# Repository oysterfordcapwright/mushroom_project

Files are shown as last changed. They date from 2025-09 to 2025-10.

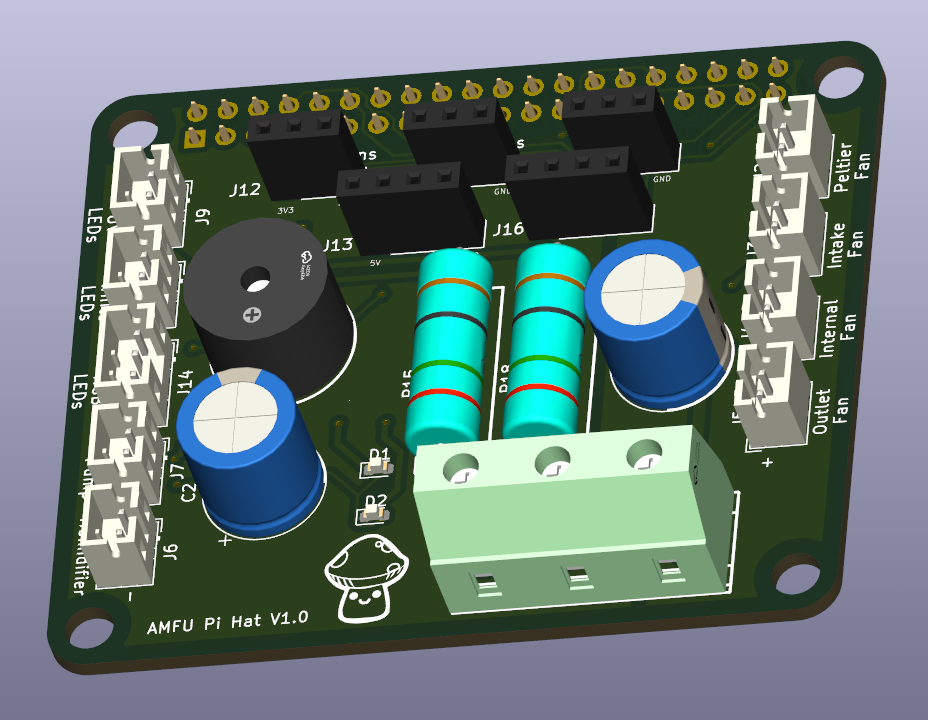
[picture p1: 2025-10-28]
hardware_design/proposed_pcb/pcb_images/PCB_3D_View.png

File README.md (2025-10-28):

# Automated Mushroom Fruiting Unit (AMFU)

A Raspberry Pi-based automated environmental control system for mushroom cultivation. This project provides precise control over temperature, humidity, CO₂ levels, and lighting to create optimal fruiting conditions for various mushroom species.

AMFU in action 

## Project Overview

The AMFU is a self-contained system that automates the fruiting stage of mushroom cultivation. It features a web-based interface for remote monitoring and control, making mushroom growing more accessible and reliable for both hobbyists and small-scale growers.

## Repository Structure

### Core Software
- **Flask Application** - Friendly web interface for system control and monitoring
- **Component Libraries** - Python drivers for all sensors and actuators:
  - Temperature and humidity sensors (DS18B20, DHT22)
  - CO₂ sensor (MH-Z19B) 
  - Lighting control (Neopixel, custom LED circuits)
  - Actuator drivers (Peltier, fans, servos, humidifier)
- **Control System** - Smart environmental management that handles parameter conflicts

### Hardware Design
- **CAD Models** - 3D printable enclosure components and mounting brackets
- **PCB Designs** - Custom Raspberry Pi hat for cleaner wiring

### Documentation
- **Component Datasheets** - Technical specifications for all hardware
- **Mushroom Results** - Yield after 1 week
- **Timelapse Examples** - Watch the mushrooms grow!

## Key Features

- **Multi-parameter control** - Temperature, humidity, CO₂, and lighting all managed automatically
- **Web-based access** - Monitor and adjust conditions from any device
- **Real-time data logging** - Watch your environmental parameters live
- **Automated time-lapse** - Capture your mushroom's growth journey
- **Contamination control** - HEPA filtration keeps chamber isolated

## Perfect For

- Home mushroom cultivation enthusiasts
- Educators teaching controlled environment agriculture
- Small-scale specialty mushroom producers
- Anyone fascinated with environmental automation

---

*Happy growing!* 🍄

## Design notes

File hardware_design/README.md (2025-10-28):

Contains the CAD .stl files and KiCad project files designed for the AMFU project.

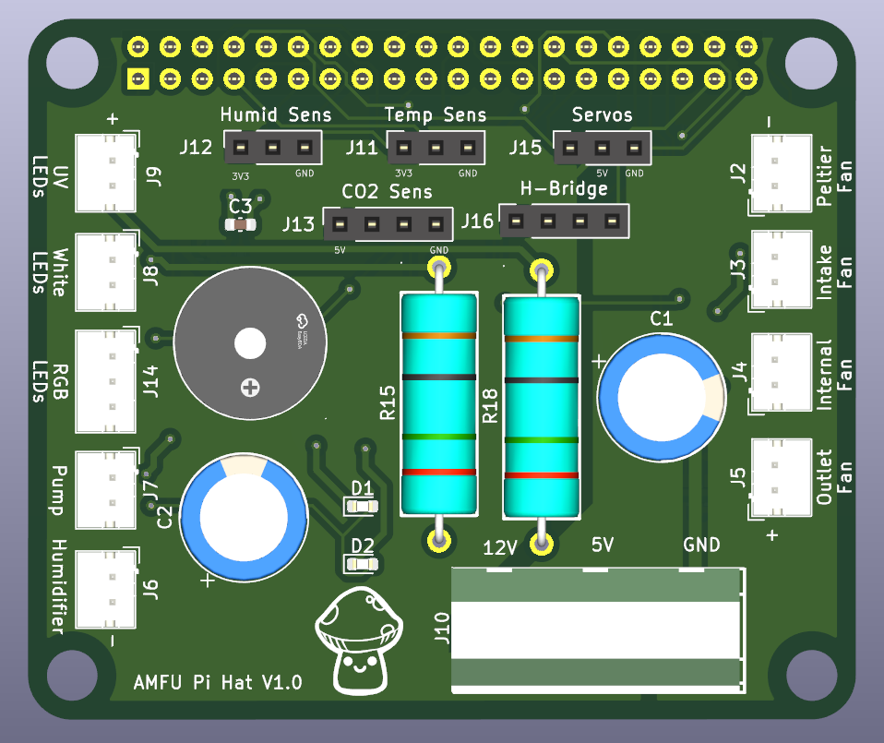
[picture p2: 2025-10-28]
hardware_design/proposed_pcb/pcb_images/PCB_Top_View.png

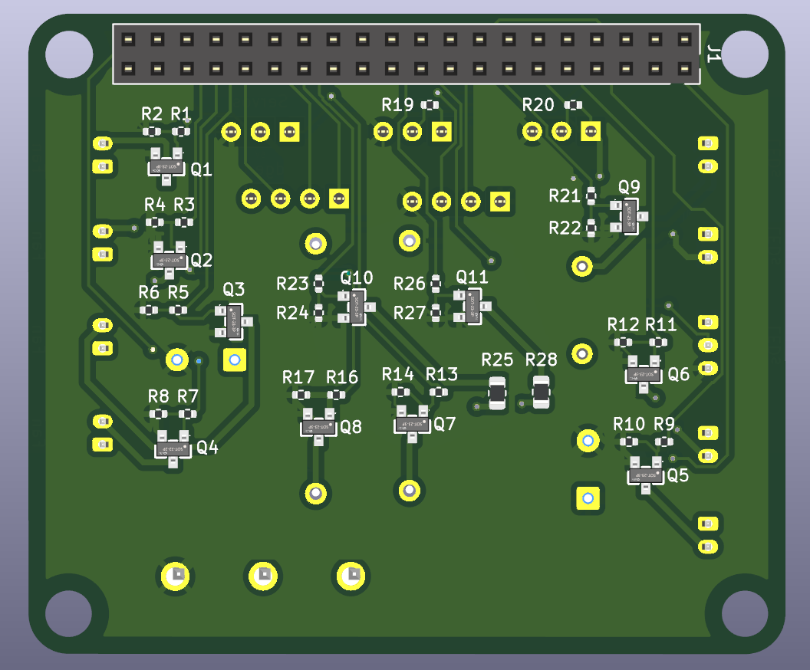
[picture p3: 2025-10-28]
hardware_design/proposed_pcb/pcb_images/PCB_Bottom_View.png

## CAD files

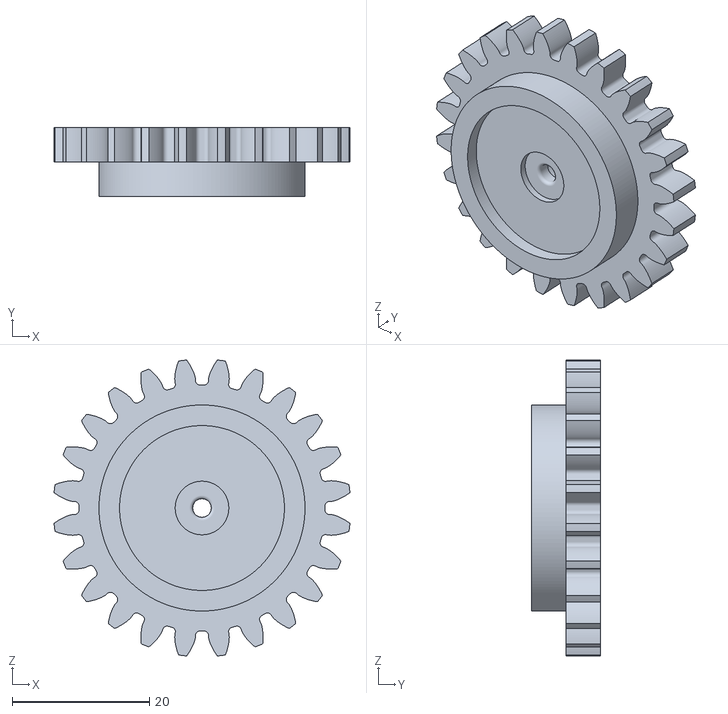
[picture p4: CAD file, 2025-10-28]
hardware_design/3d_cad_files/Airway Slider - Spur Gear.stl
43.1 x 10.0 x 43.1

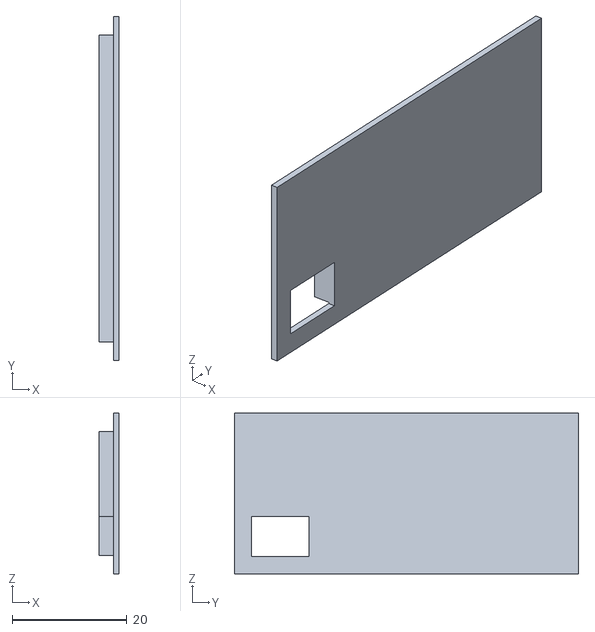
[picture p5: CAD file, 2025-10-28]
hardware_design/3d_cad_files/Humidifier Circuit Housing - Lid.stl
3.50 x 60.0 x 28.0

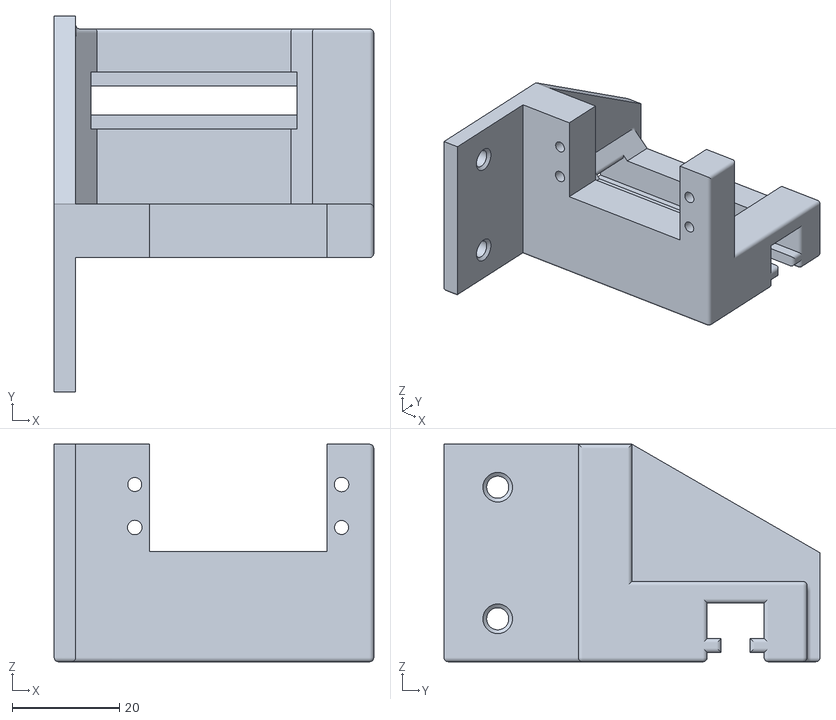
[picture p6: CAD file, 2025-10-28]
hardware_design/3d_cad_files/Airway Slider - Servo Bracket.stl
59.5 x 70.0 x 40.5

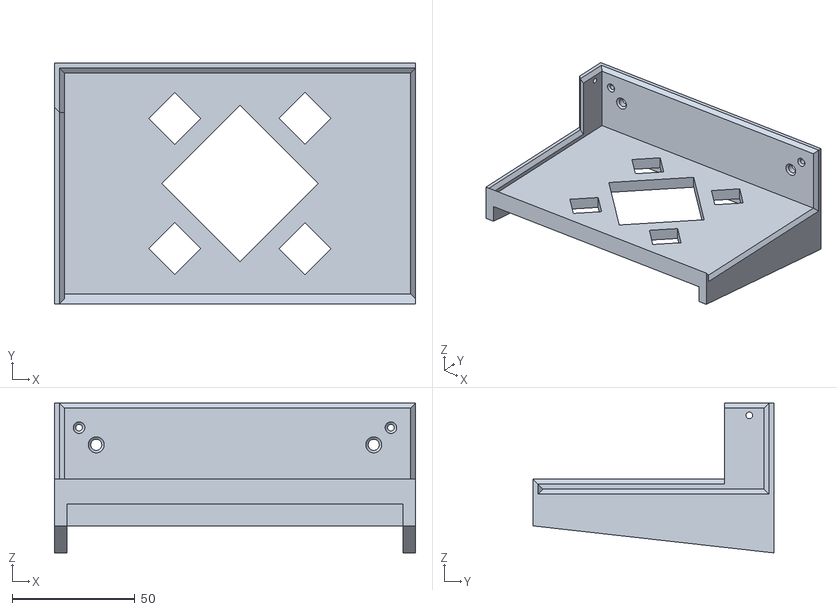
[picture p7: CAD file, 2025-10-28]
hardware_design/3d_cad_files/PSU Bracket - Bottom.stl
147.0 x 98.0 x 61.0

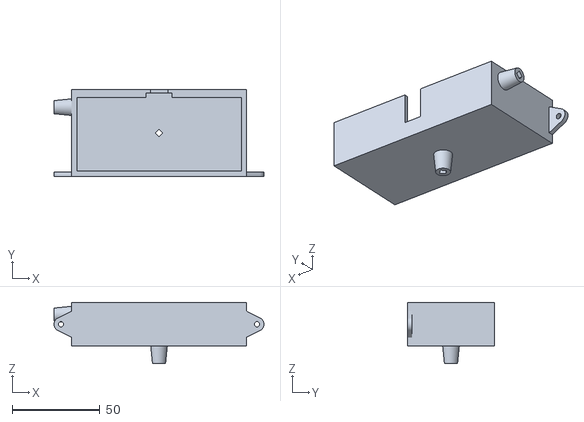
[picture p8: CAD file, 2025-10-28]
hardware_design/3d_cad_files/Water Reservoir - Body.stl
120.0 x 49.5 x 35.0

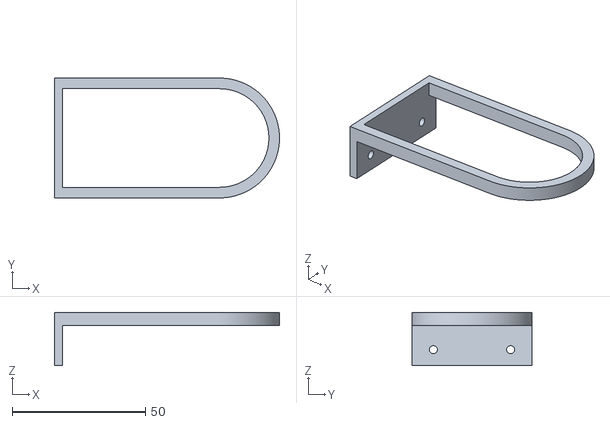
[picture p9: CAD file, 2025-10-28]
hardware_design/3d_cad_files/Plate Support.stl
84.5 x 45.0 x 20.0

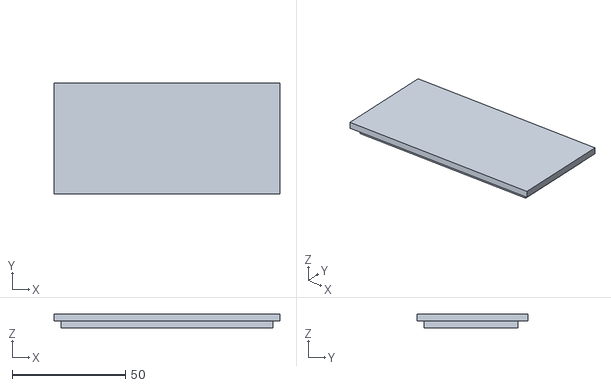
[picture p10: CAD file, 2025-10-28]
hardware_design/3d_cad_files/Water Reservoir - Lid.stl
99.6 x 49.1 x 6.00

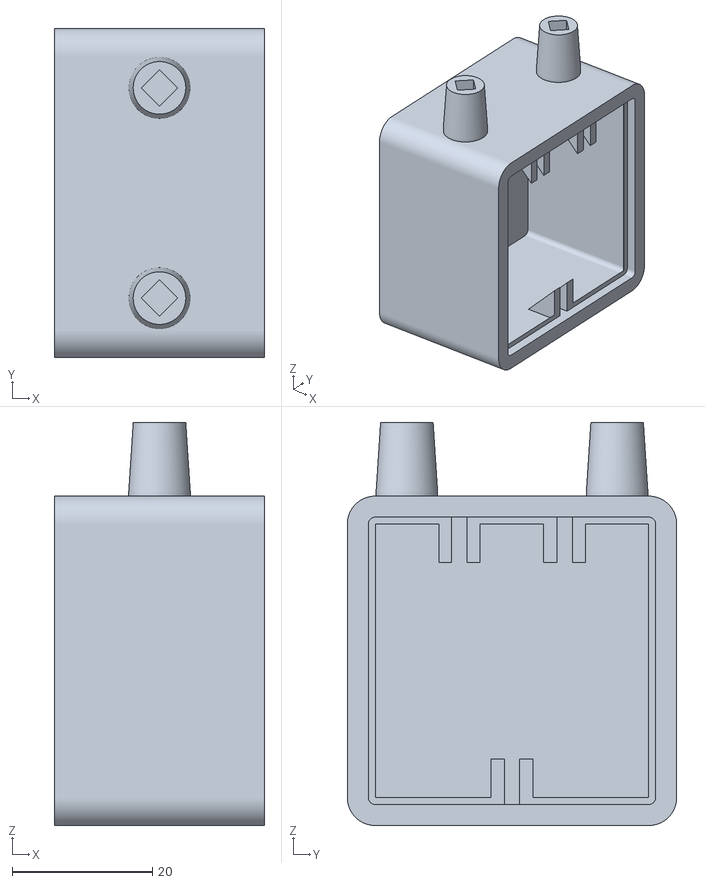
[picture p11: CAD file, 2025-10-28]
hardware_design/3d_cad_files/Water Cooling Block.stl
30.0 x 47.0 x 57.5

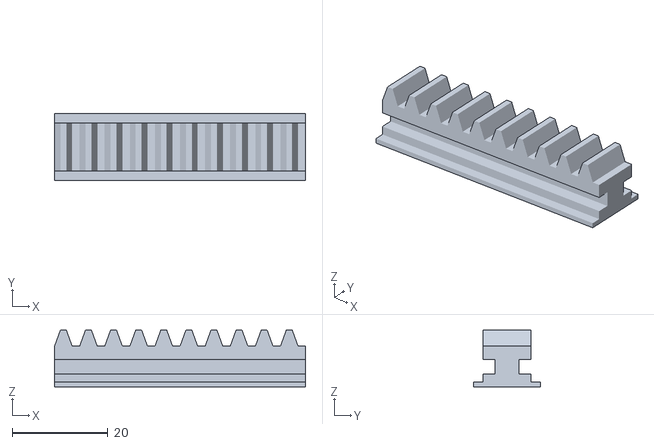
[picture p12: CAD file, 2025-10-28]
hardware_design/3d_cad_files/Airway Slider - Rack.stl
52.4 x 14.0 x 11.9

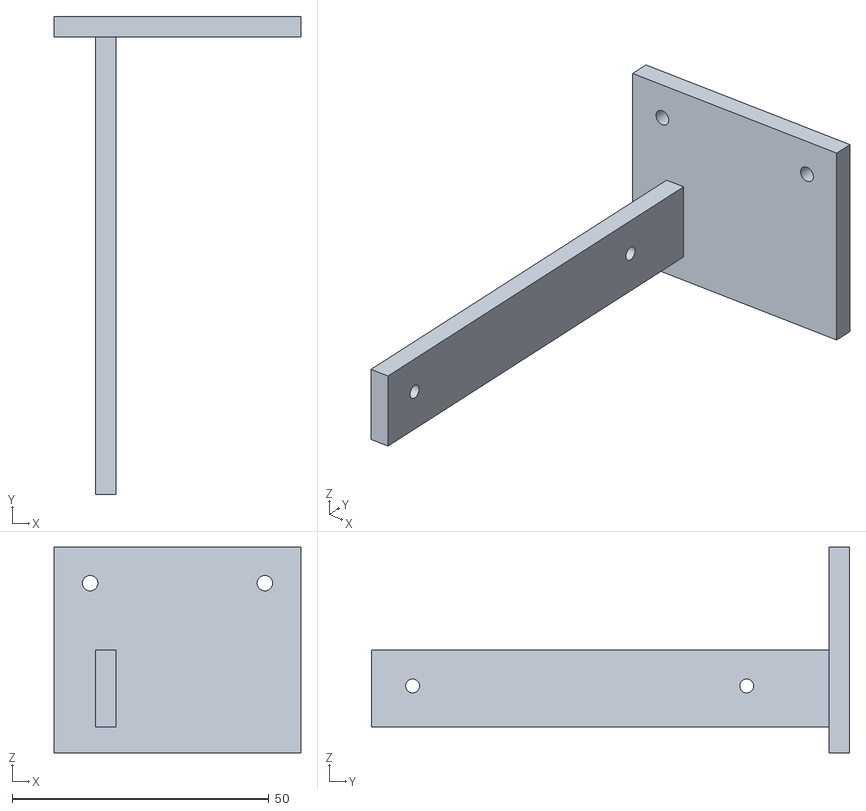
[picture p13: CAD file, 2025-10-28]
hardware_design/3d_cad_files/PSU Bracket - Top.stl
48.0 x 93.0 x 40.0

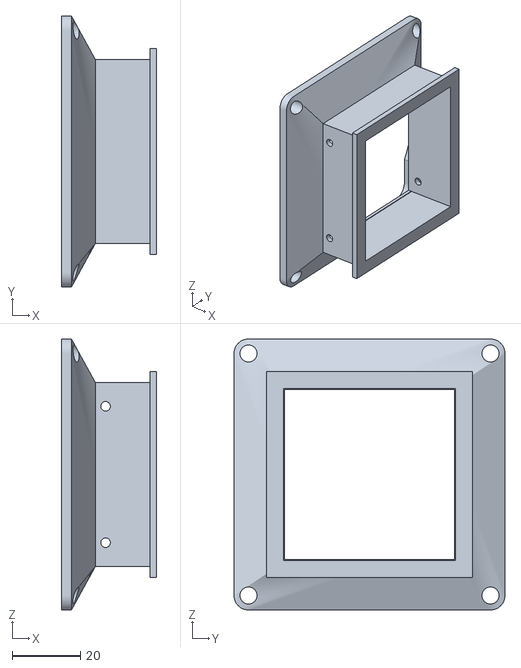
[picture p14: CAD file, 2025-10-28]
hardware_design/3d_cad_files/Airway Slider - Fan Bracket.stl
28.0 x 79.5 x 79.5

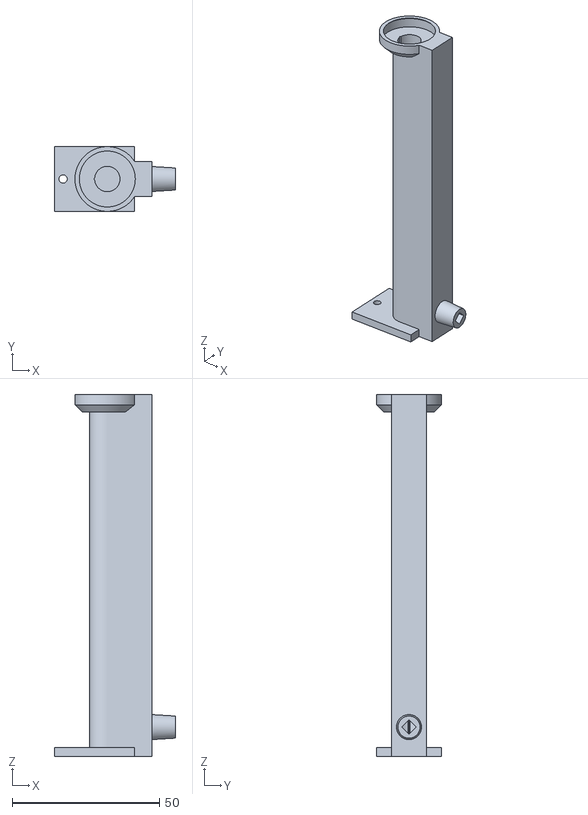
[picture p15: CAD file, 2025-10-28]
hardware_design/3d_cad_files/Humidifier Housing.stl
41.2 x 22.0 x 123.0

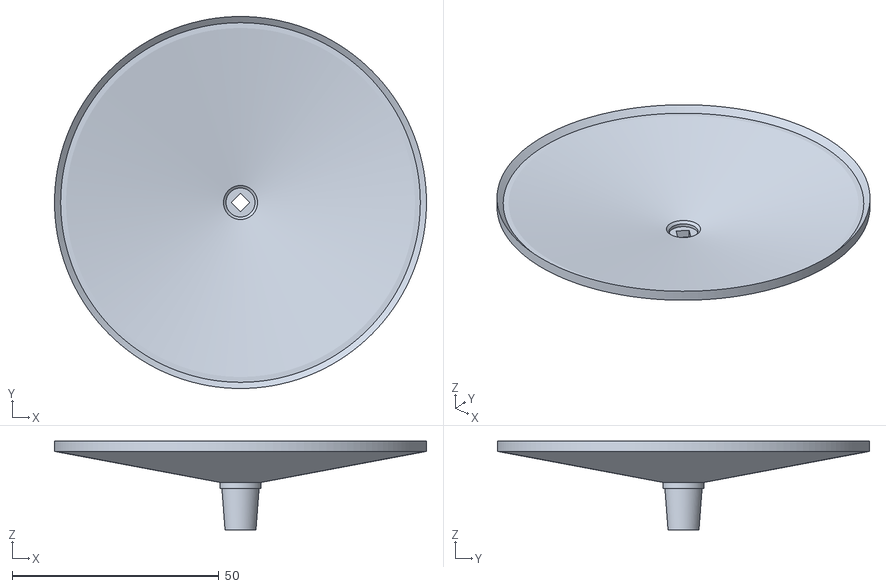
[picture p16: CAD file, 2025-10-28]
hardware_design/3d_cad_files/Condensation Catchment Plate.stl
90.0 x 90.0 x 21.5

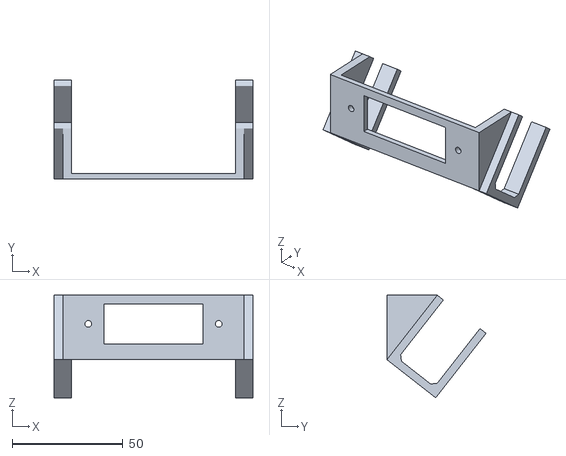
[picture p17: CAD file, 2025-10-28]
hardware_design/3d_cad_files/Camera Mount.stl
90.0 x 44.8 x 46.4

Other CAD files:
hardware_design/3d_cad_files/Water Cooling Mount.stl
hardware_design/3d_cad_files/Humidifier Circuit Housing - Body.stl
hardware_design/3d_cad_files/Airway Slider - Airflow Passage.stl
hardware_design/3d_cad_files/Airway Slider - Aiflow Plug.stl

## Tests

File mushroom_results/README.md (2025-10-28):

Contains the timelapse and final yield of a 1 week test conducted on the AMFU using grey oyster mushrooms.

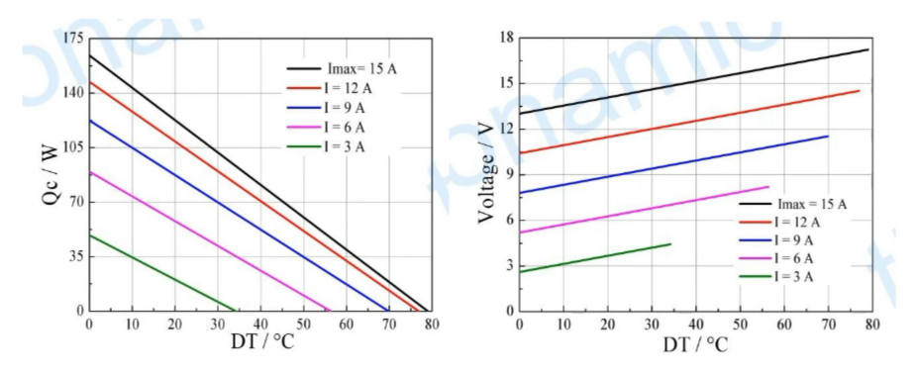
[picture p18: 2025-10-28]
documentation/12715 Characteristics.png

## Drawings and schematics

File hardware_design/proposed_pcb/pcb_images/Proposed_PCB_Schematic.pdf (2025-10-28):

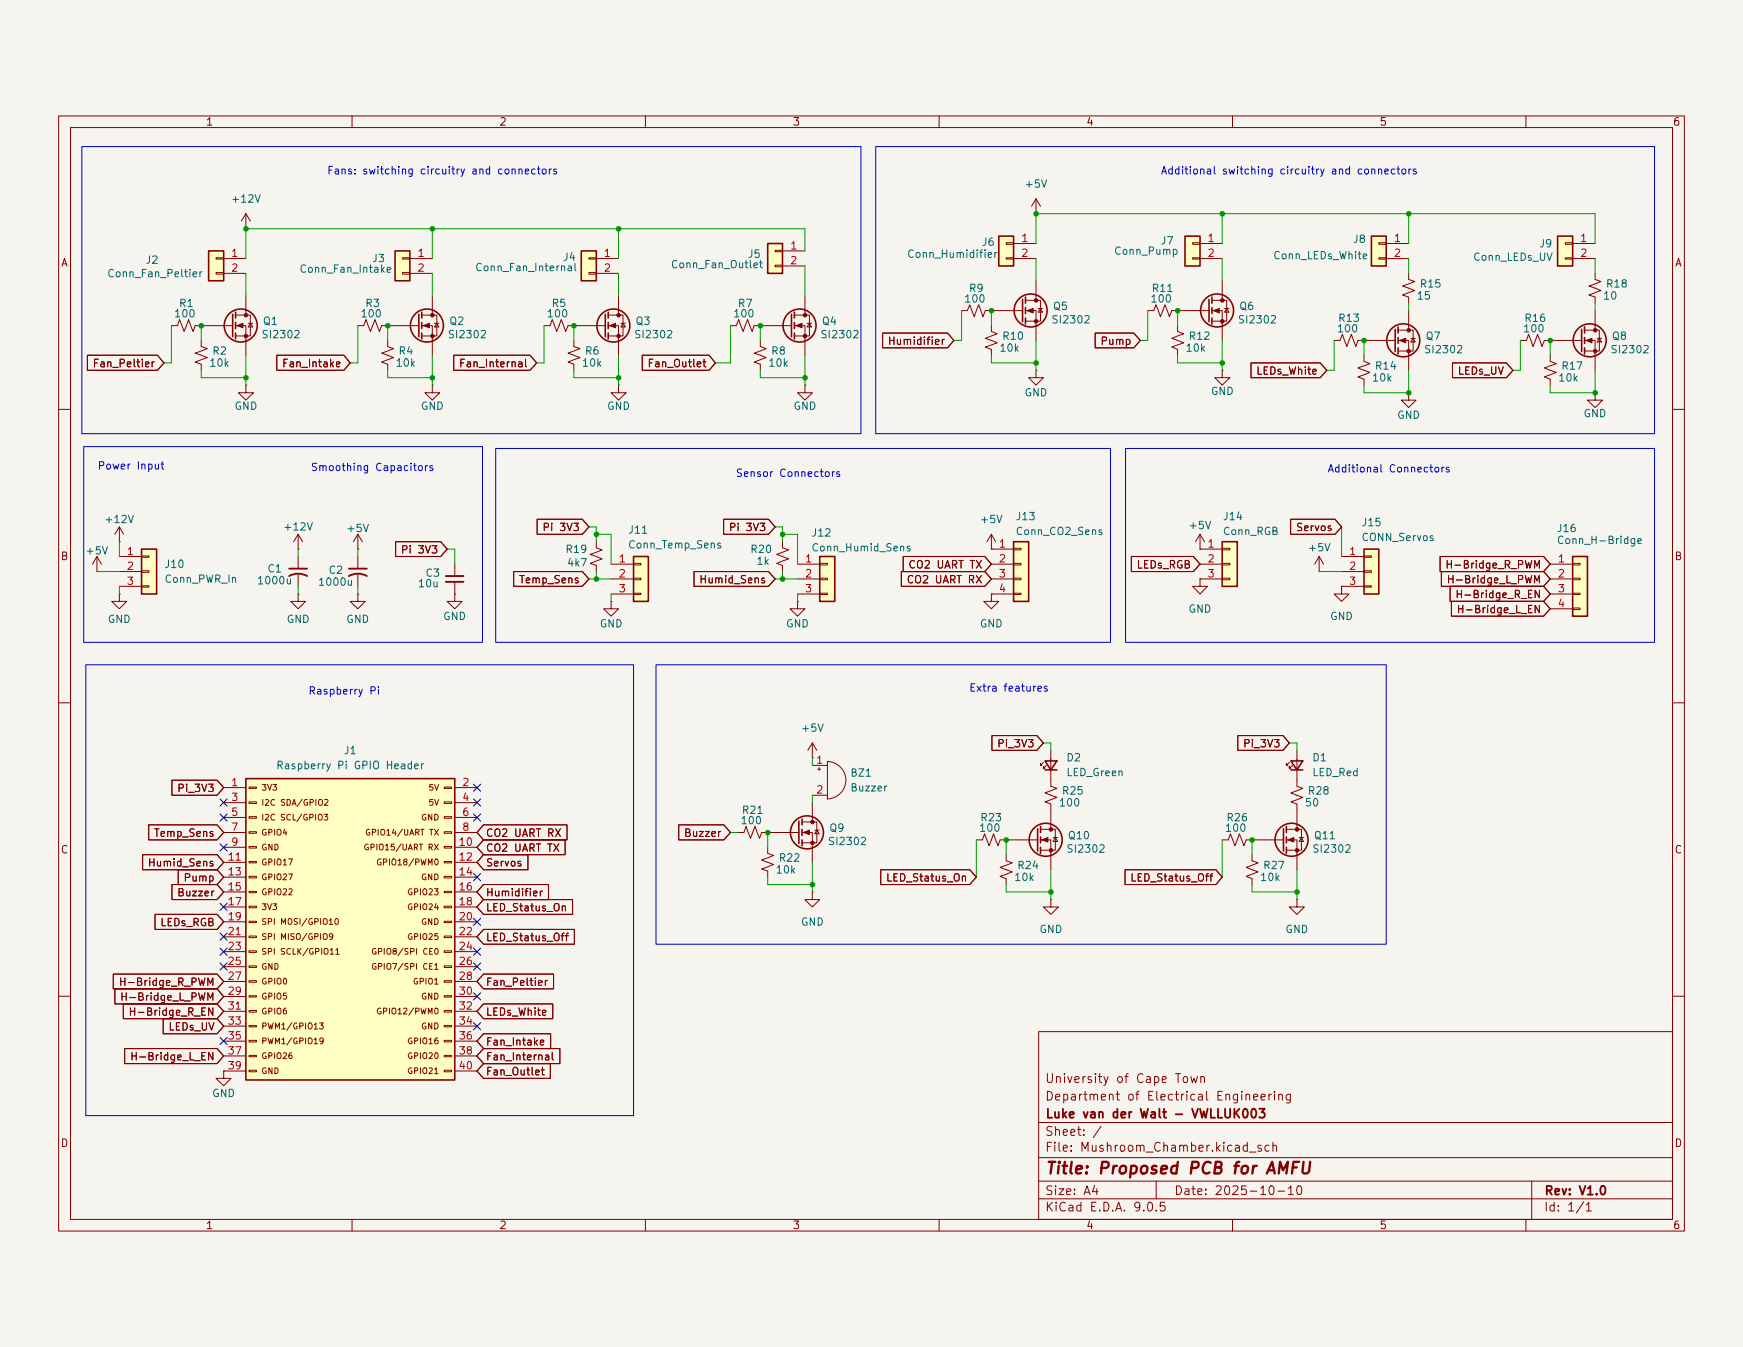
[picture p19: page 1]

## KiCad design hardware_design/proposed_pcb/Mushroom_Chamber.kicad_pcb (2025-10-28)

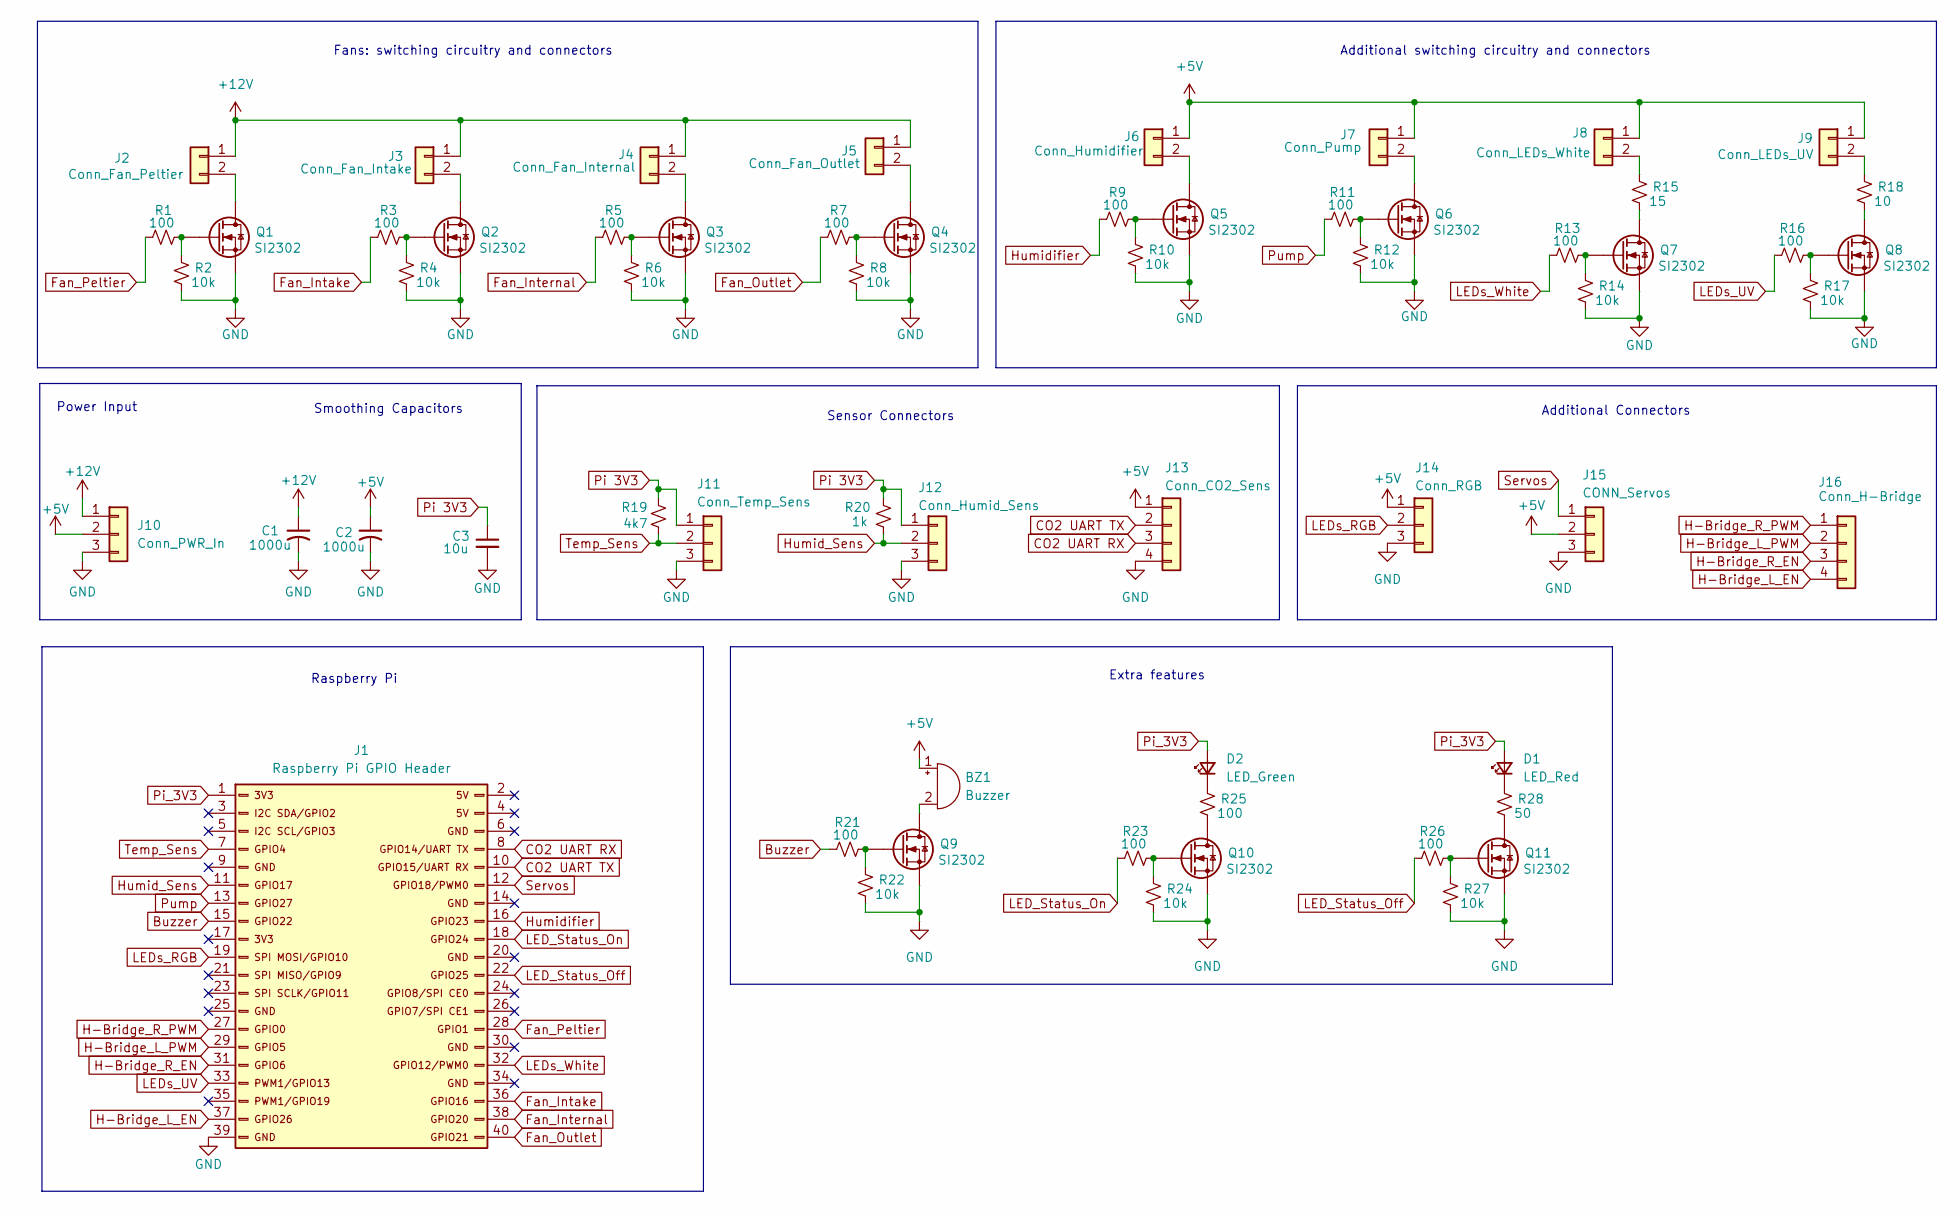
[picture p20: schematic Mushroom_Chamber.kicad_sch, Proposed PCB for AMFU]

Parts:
BZ1: Buzzer; BUZ-TH_BD12.0-P7.60-D0.6-FD
C1, C2: 1000u; CP_Radial_D10.0mm_P5.00mm
C3: 10u; C_0603_1608Metric
D1: LED_Red; LED_0603_1608Metric
D2: LED_Green; LED_0603_1608Metric
J1: Raspberry Pi GPIO Header; PinSocket_2x20_P2.54mm_Vertical
J2: Conn_Fan_Peltier; JST_PH_B2B-PH-K_1x02_P2.00mm_Vertical
J3: Conn_Fan_Intake; JST_PH_B2B-PH-K_1x02_P2.00mm_Vertical
J4: Conn_Fan_Internal; JST_PH_B2B-PH-K_1x02_P2.00mm_Vertical
J5: Conn_Fan_Outlet; JST_PH_B2B-PH-K_1x02_P2.00mm_Vertical
J6: Conn_Humidifier; JST_PH_B2B-PH-K_1x02_P2.00mm_Vertical
J7: Conn_Pump; JST_PH_B2B-PH-K_1x02_P2.00mm_Vertical
J8: Conn_LEDs_White; JST_PH_B2B-PH-K_1x02_P2.00mm_Vertical
J9: Conn_LEDs_UV; JST_PH_B2B-PH-K_1x02_P2.00mm_Vertical
J10: Conn_PWR_In; CONN-TH_3P-P7.62_1717732
J11: Conn_Temp_Sens; PinSocket_1x03_P2.54mm_Vertical
J12: Conn_Humid_Sens; PinSocket_1x03_P2.54mm_Vertical
J13: Conn_CO2_Sens; PinSocket_1x04_P2.54mm_Vertical
J14: Conn_RGB; JST_PH_B3B-PH-K_1x03_P2.00mm_Vertical
J15: CONN_Servos; PinSocket_1x03_P2.54mm_Vertical
J16: Conn_H-Bridge; PinSocket_1x04_P2.54mm_Vertical
Q1, Q2, Q3, Q4, Q5, Q6, Q7, Q8, Q9, Q10, Q11: SI2302; SOT-23_L2.9-W1.3-P1.90-LS2.4-BR
R1, R3, R5, R7, R9, R11, R13, R16, R21, R23, R26: 100; R_0402_1005Metric
R2, R4, R6, R8, R10, R12, R14, R17, R22, R24, R27: 10k; R_0402_1005Metric
R15: 15; RES-TH_BD6.0-L17.5-P21.50-D0.7
R18: 10; RES-TH_BD6.0-L17.5-P21.50-D0.7
R19: 4k7; R_0402_1005Metric
R20: 1k; R_0402_1005Metric
R25: 100; R_0805_2012Metric
R28: 50; R_0805_2012Metric

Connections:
+5V: BZ1.1 (+), C2.1, J6.1, J7.1, J8.1, J9.1, J10.2, J13.1, J14.1, J15.2
+12V: C1.1, J2.1, J3.1, J4.1, J5.1, J10.1
Buzzer: J1.15, R21.1
CO2 UART RX: J1.8, J13.3
CO2 UART TX: J1.10, J13.2
Fan_Intake: J1.36, R3.1
Fan_Internal: J1.38, R5.1
Fan_Outlet: J1.40, R7.1
Fan_Peltier: J1.28, R1.1
GND: C1.2, C2.2, C3.2, J1.39, J10.3, J11.3, J12.3, J13.4, J14.3, J15.3, Q1.2 (S), Q2.2 (S), Q3.2 (S), Q4.2 (S), Q5.2 (S), Q6.2 (S), Q7.2 (S), Q8.2 (S), Q9.2 (S), Q10.2 (S), Q11.2 (S), R2.2, R4.2, R6.2, R8.2, R10.2, R12.2, R14.2, R17.2, R22.2, R24.2, R27.2
H-Bridge_L_EN: J1.37, J16.4
H-Bridge_L_PWM: J1.29, J16.2
H-Bridge_R_EN: J1.31, J16.3
H-Bridge_R_PWM: J1.27, J16.1
Humid_Sens: J1.11, J12.2, R20.2
Humidifier: J1.16, R9.1
LED_Status_Off: J1.22, R26.1
LED_Status_On: J1.18, R23.1
LEDs_RGB: J1.19, J14.2
LEDs_UV: J1.33, R16.1
LEDs_White: J1.32, R13.1
unnamed: BZ1.2 (-), Q9.3 (D)
unnamed: D1.1 (K), R28.1
unnamed: D2.1 (K), R25.1
unnamed: J2.2, Q1.3 (D)
unnamed: J3.2, Q2.3 (D)
unnamed: J4.2, Q3.3 (D)
unnamed: J5.2, Q4.3 (D)
unnamed: J6.2, Q5.3 (D)
unnamed: J7.2, Q6.3 (D)
unnamed: J8.2, R15.1
unnamed: J9.2, R18.1
unnamed: Q1.1 (G), R1.2, R2.1
unnamed: Q2.1 (G), R3.2, R4.1
unnamed: Q3.1 (G), R5.2, R6.1
unnamed: Q4.1 (G), R7.2, R8.1
unnamed: Q5.1 (G), R9.2, R10.1
unnamed: Q6.1 (G), R11.2, R12.1
unnamed: Q7.3 (D), R15.2
unnamed: Q7.1 (G), R13.2, R14.1
unnamed: Q8.3 (D), R18.2
unnamed: Q8.1 (G), R16.2, R17.1
unnamed: Q9.1 (G), R21.2, R22.1
unnamed: Q10.3 (D), R25.2
unnamed: Q10.1 (G), R23.2, R24.1
unnamed: Q11.3 (D), R28.2
unnamed: Q11.1 (G), R26.2, R27.1
Pi 3V3: C3.1, J11.1, J12.1, R19.1, R20.1
Pi_3V3: D1.2 (A), D2.2 (A), J1.1
Pump: J1.13, R11.1
Servos: J1.12, J15.1
Temp_Sens: J1.7, J11.2, R19.2

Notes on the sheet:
Sensor Connectors
Extra features
Power Input
Fans: switching circuitry and connectors
Raspberry Pi
Additional switching circuitry and connectors
Additional Connectors
Smoothing Capacitors

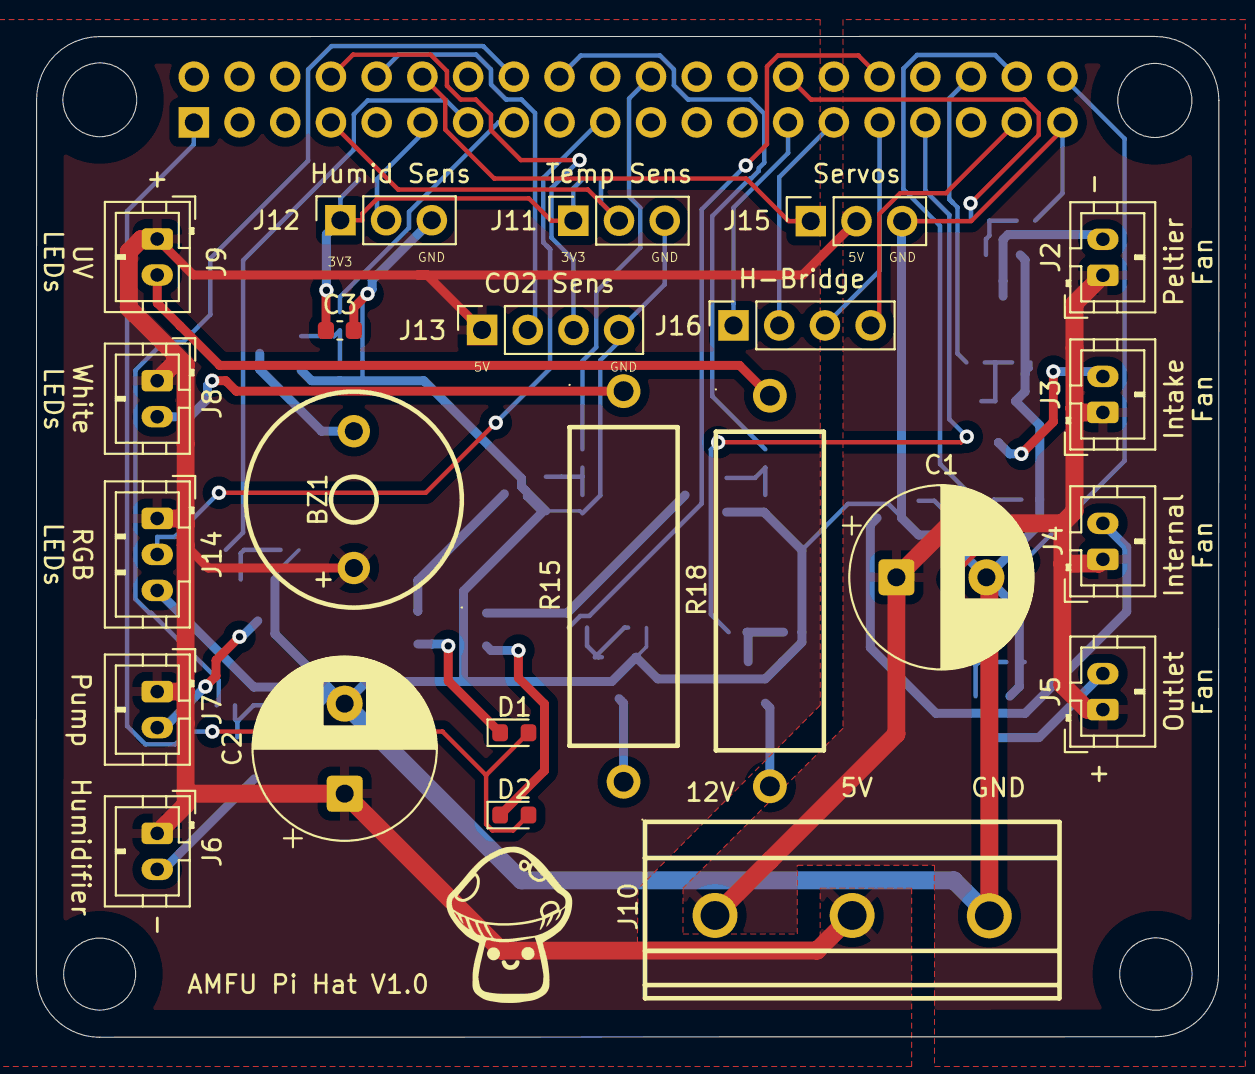
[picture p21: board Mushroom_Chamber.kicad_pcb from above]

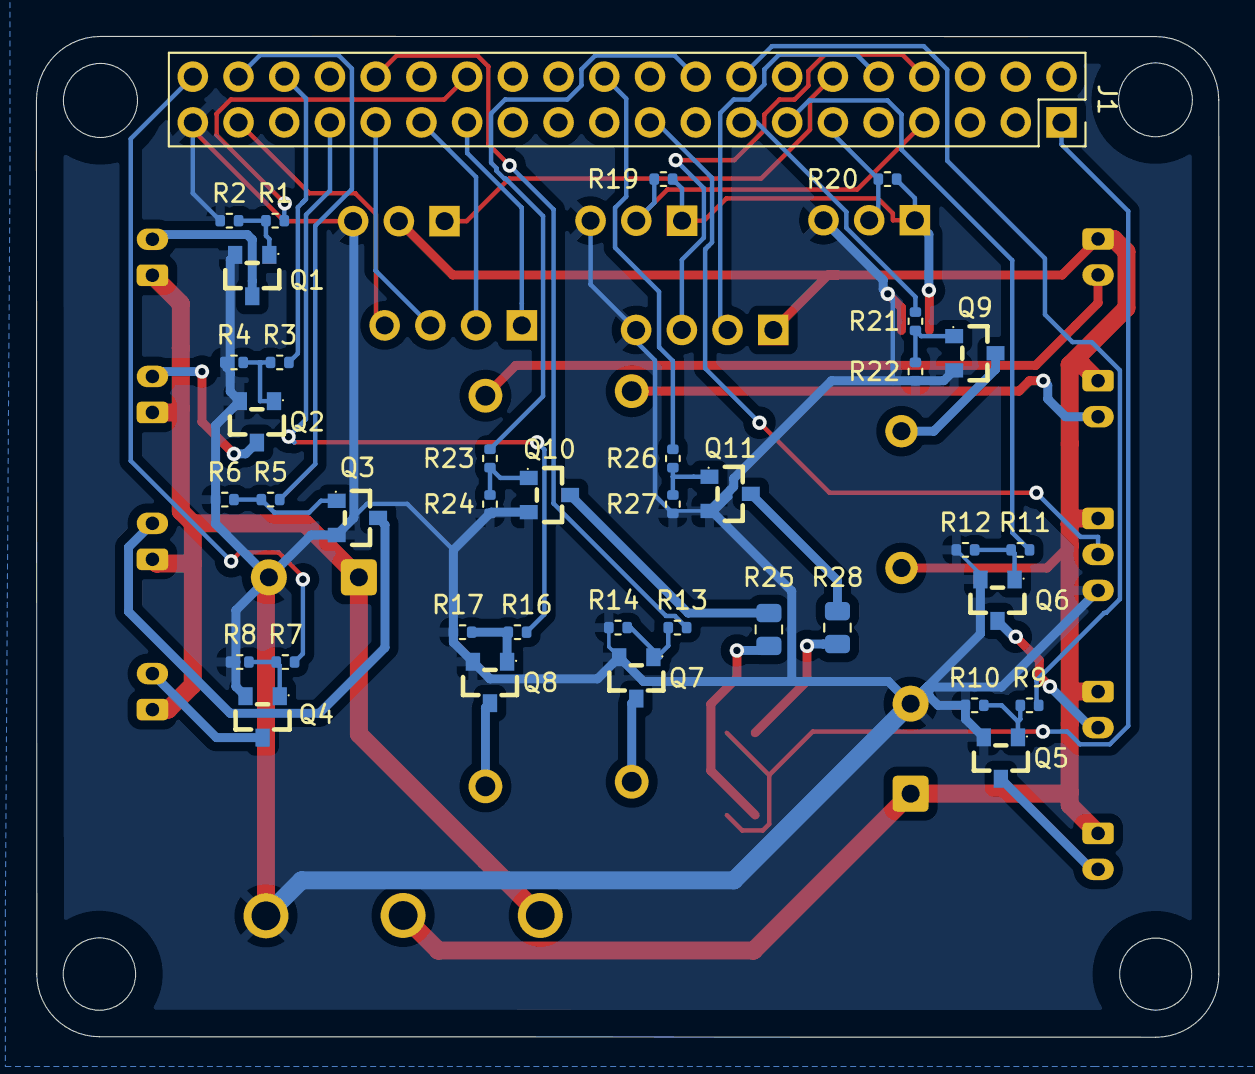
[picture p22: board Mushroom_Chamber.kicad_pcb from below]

Board: 2 copper layers, 65.7 x 55.6 mm, 61 parts (38 on the bottom side), 52 nets.

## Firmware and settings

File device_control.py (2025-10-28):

import time
import board
import neopixel_spi as neopixel
from rpi_hardware_pwm import HardwarePWM
from gpiozero import PWMOutputDevice, DigitalOutputDevice
from DS18B20 import get_DS_temp
from CO2_sensor import get_CO2_data
from DHT22 import get_DHT22_data
import smbus2
import math


# Pin Mapping with Labels
PIN_CONFIG = {
    "water_pump": 27,
    "white_leds": 12,       # Hardware PWM (channel 0)
    "uv_leds": 13,          # Hardware PWM (channel 1)
    "peltier_fan": 1,
    "intake_fan": 16,
    "outflow_fan": 21,
    "internal_fan": 20,
    "humidifier": 23,
}

# Servos config
MIN_DC = 4.5    
MAX_DC = 10     

# H-bridge config
LEFT_ENABLE_PIN = 26
RIGHT_ENABLE_PIN = 6
LEFT_PWM_PIN = 5
RIGHT_PWM_PIN = 0


# ================================
# Device Controller Class
# ================================
class DeviceController:
    def __init__(self):
        self.devices = {}

        # Setup gpiozero PWM devices (excluding hardware PWM pins)
        for label, pin in PIN_CONFIG.items():
            if pin not in (13, 12, 18):  # hardware PWM handled separately
                if label in ("water_pump", "humidifier"):
                    self.devices[label] = DigitalOutputDevice(pin)
                else:
                    self.devices[label] = PWMOutputDevice(pin, frequency=20)

        # Setup hardware PWM LEDs
        self.devices["white_leds"] = HardwarePWM(pwm_channel=0, hz=1000, chip=0)
        self.devices["uv_leds"] = HardwarePWM(pwm_channel=1, hz=1000, chip=0)

        # Start LED PWM at 0% duty
        self.devices["white_leds"].start(0)
        self.devices["uv_leds"].start(0)
        
        # Setup servos on hardware PWM
        self._servo_pwm = HardwarePWM(pwm_channel=2, hz=50, chip=0)
        self._servo_pwm.start(self._angle_to_dc(0))  # start closed (default state) 
        self._servo_angle = 0

        
        # NeoPixel SPI Setup
        self.NEO_NUM_PIXELS = 12 
        self.COLOR_MAP = {
            "red": (255, 0, 0),
            "green": (0, 255, 0),
            "blue": (0, 0, 255),
            "yellow": (255, 255, 0),
            "cyan": (0, 255, 255),
            "magenta": (255, 0, 255),
            "white": (255, 255, 255),
            "orange": (255, 165, 0),
            "purple": (128, 0, 128),
            "off": (0, 0, 0)
        }
        self.neopixels = neopixel.NeoPixel_SPI(
            board.SPI(),
            self.NEO_NUM_PIXELS,
            brightness=0.2,
            auto_write=False,
        )
        self.neopixel_state = [(0, 0, 0)] * self.NEO_NUM_PIXELS
        self.neopixels.fill((0, 0, 0))
        self.neopixels.show()

        # Setup peltier H-bridge
        self.left_enable = DigitalOutputDevice(LEFT_ENABLE_PIN)
        self.right_enable = DigitalOutputDevice(RIGHT_ENABLE_PIN)
        self.left_pwm = PWMOutputDevice(LEFT_PWM_PIN, frequency=40)
        self.right_pwm = PWMOutputDevice(RIGHT_PWM_PIN, frequency=40)

    # ================================
    # Control Functions
    # ================================
    def set_pwm(self, label, duty_cycle: float):
        """
        Set PWM duty cycle for a device.
        duty_cycle: float 0.0-1.0 for gpiozero devices
                    float 0.0-100.0 for hardware PWM 
        """
        if label not in self.devices:
            raise ValueError(f"Unknown device label: {label}")

        dev = self.devices[label]

        if isinstance(dev, HardwarePWM):
            dev.change_duty_cycle(duty_cycle)  # expects 0-100
        else:
            dev.value = duty_cycle  # expects 0.0-1.0

    def turn_on(self, label):
        self.set_pwm(label, 1.0 if not isinstance(self.devices[label], HardwarePWM) else 100.0)

    def turn_off(self, label):
        self.set_pwm(label, 0.0)


    # ================================
    # Servo Control
    # ================================
    def _angle_to_dc(self, angle):
        """Map angle (0-180°) to duty cycle usually."""
        return MIN_DC + (angle / 180.0) * (MAX_DC - MIN_DC)

    def set_servo_angle(self, angle):
        """Set angle in degrees (0-180). Controls both servos since same pin."""
        clamped = max(0, min(180, angle))
        self._servo_pwm.change_duty_cycle(self._angle_to_dc(clamped))
        self._servo_angle = clamped

    def stop_servo(self):
        """Turn off the servo PWM signal (both servos stop holding)."""
        self._servo_pwm.stop()


    # ================================
    # H-Bridge Control
    # ================================
    def peltier_enable(self, left=True, right=True):
        self.left_enable.value = 1 if left else 0
        self.right_enable.value = 1 if right else 0

    def peltier_disable(self):
        self.left_enable.off()
        self.right_enable.off()

    def set_peltier_pwm(self, power, direction="cool"):
        """
        Control H-bridge motor with PWM.
        power: 0.0 - 1.0 (duty cycle)
        direction: "forward" or "backward"
        """
        if direction == "cool":
            # Left side idle, right side drives
            self.left_pwm.value = 0.0
            self.right_pwm.value = power
        elif direction == "heat":
            # Right side idle, left side drives
            self.right_pwm.value = 0.0
            self.left_pwm.value = power
        else:
            # Stop: both off, disable outputs
            self.left_pwm.value = 0.0
            self.right_pwm.value = 0.0
            self.left_enable.off()
            self.right_enable.off()


    # ================================
    # NeoPixel Control
    # ================================
    def set_neopixel_color(self, color_name, pixel_indices=None):
        """
        Set NeoPixel color by name.
        color_name: str from COLOR_MAP
        pixel_indices: list of indices to update, None = all
        """
        color = self.COLOR_MAP.get(color_name.lower())
        if color is None:
            raise ValueError(f"Unknown color '{color_name}'. Valid options: {list(self.COLOR_MAP.keys())}")

        if pixel_indices is None:
            self.neopixels.fill(color)
            self.neopixel_state = [color] * self.NEO_NUM_PIXELS
        else:
            for i in pixel_indices:
                if 0 <= i < self.NEO_NUM_PIXELS:
                    self.neopixels[i] = color
                    self.neopixel_state[i] = color

        self.neopixels.show()

    def set_neopixel_brightness(self, brightness):
        """
        Set brightness for all NeoPixels.
        brightness: float 0.0 (off) to 1.0 (full brightness)
        """
        if not 0.0 <= brightness <= 1.0:
            raise ValueError("Brightness must be between 0.0 and 1.0")
        
        self.neopixels.brightness = brightness
        self.neopixels.show()


    # ================================
    # State Getters
    # ================================
    def get_state(self, label):
        """
        Get the current state (duty cycle or on/off) of a device by label.
        Returns:
            - float: duty cycle (0.0-1.0 for gpiozero, 0-100 for HardwarePWM)
            - bool: True/False for DigitalOutputDevice
        """
        if label not in self.devices:
            raise ValueError(f"Unknown device label: {label}")

        dev = self.devices[label]

        if isinstance(dev, HardwarePWM):
            return dev.duty_cycle  # already 0-100
        elif isinstance(dev, PWMOutputDevice):
            return dev.value       # 0.0-1.0
        elif isinstance(dev, DigitalOutputDevice):
            return dev.value       # 0/1 (False/True)
        else:
            return None

    def get_servo_angle(self):
        """Return the last commanded servo angle in degrees."""
        return self._servo_angle

    def get_peltier_state(self):
        """
        Return a dict describing the Peltier's state.
        Includes mode ('cool', 'heat', 'off') and current duty cycle.
        """
        left_val = self.left_pwm.value
        right_val = self.right_pwm.value

        if left_val > 0 and right_val == 0:
            mode = "heat"
            duty = left_val
        elif right_val > 0 and left_val == 0:
            mode = "cool"
            duty = right_val
        else:
            mode = "off"
            duty = 0.0

        return {
            "mode": mode,
            "duty_cycle": duty,   # 0.0-1.0
            "enabled": (self.left_enable.value or self.right_enable.value)
        }

    def get_neopixel_state(self, index=None):
        """
        Get NeoPixel state.
        index: None returns full list, else return color of that pixel
        """
        if index is None:
            return self.neopixel_state
        elif 0 <= index < self.NEO_NUM_PIXELS:
            return self.neopixel_state[index]
        else:
            raise ValueError(f"Pixel index {index} out of range (0-{self.NEO_NUM_PIXELS-1})")


    # ================================
    # Cleanup
    # ================================
    def cleanup(self):

        # Turn off NeoPixels first
        if hasattr(self, "neopixels"):
            self.neopixels.fill((0, 0, 0))
            self.neopixels.show()
            self.neopixel_state = [(0, 0, 0)] * self.NEO_NUM_PIXELS
        
        # Stop and close other devices
        for dev in self.devices.values():
            if isinstance(dev, HardwarePWM):
                dev.stop()
            else:
                dev.close()

        # Stop servos
        if hasattr(self, "_servo_pwm"):
            dev.change_duty_cycle(self._angle_to_dc(0)) 
            time.sleep(0.5)  # give time to physically move
            self._servo_pwm.stop()
        
         # Close peltier H-bridge
        self.left_pwm.close()
        self.right_pwm.close()
        self.left_enable.close()
        self.right_enable.close()

def gxhtc3_read():
    try:
        bus.write_i2c_block_data(0x70, 0x35, [0x17])
        time.sleep(0.001)  # Short delay after wake-up
    
        bus.write_i2c_block_data(0x70, 0x7C, [0xA2])
        time.sleep(0.02) 
        data = bus.read_i2c_block_data(0x70, 0x00, 6)
        
        bus.write_i2c_block_data(0x70, 0xB0, [0x98])
        
        # Extract and convert values
        temp_raw = (data[0] << 8) | data[1]
        hum_raw = (data[3] << 8) | data[4]
        
        temp = -45 + (175 * temp_raw / 65535.0)
        hum = 100 * hum_raw / 65535.0
        
        return temp, hum
        
    except Exception as e:
        print(f"GXHTC3 error: {e}")
        return None, None


if __name__ == "__main__":
    
    try:
        dc = DeviceController()
        

        # Set white LEDs (hardware PWM)
        # dc.set_pwm("white_leds", 80)
        # dc.set_pwm("uv_leds", 80)  # 50% brightness

        # Set all pixels to red
        # dc.set_neopixel_color("red")
        # time.sleep(3)

        # # Set pixels 0 and 1 to blue
        # dc.set_neopixel_color("blue", pixel_indices=[0,1])
        # time.sleep(3)


        # Use H-bridge
        # dc.peltier_enable()
        # dc.set_peltier_pwm(1, "cool")  # forward
        dc.turn_on("peltier_fan")
        dc.turn_on("water_pump")
        # dc.turn_on("humidifier")
        dc.turn_on("internal_fan")
        # dc.turn_on("intake_fan")
        # dc.turn_on("outflow_fan")
        # dc.set_servo_angle(360)
        # t=0

        bus = smbus2.SMBus(1)

        while True:
            temperatures = get_DS_temp()
            CO2_data = get_CO2_data()
            humid_data = get_DHT22_data()
            gxhtc3_temp, gxhtc3_hum = gxhtc3_read()
            
            print("\n" + "="*50)
            print("SENSOR COMPARISON -", time.strftime("%H:%M:%S"))
            print("="*50)
            
            print("TEMPERATURE SENSORS:")
            print(f"  DS18B20 - Probe1...{temperatures['Probe1']:.1f}°C")
            print(f"  DS18B20 - Probe2...{temperatures['Probe2']:.1f}°C") 
            print(f"  DS18B20 - Probe3...{temperatures['Probe3']:.1f}°C")
            print(f"  CO2 Sensor.........{CO2_data['temperature']:.0f}°C")
            print(f"  DHT22..............{humid_data['temperature']-0.7:.1f}°C")
            print(f"  GXHTC3.............{gxhtc3_temp:.1f}°C" if gxhtc3_temp else "  GXHTC3:          Failed")
            print()
            print("HUMIDITY SENSORS:")
            print(f"  DHT22..............{humid_data['humidity']:.1f}%")
            print(f"  GXHTC3.............{gxhtc3_hum:.1f}%" if gxhtc3_hum else "  GXHTC3:   Failed")
            
            # print("="*50)
            
            time.sleep(2)
        #     t=t+1
            
        #     dc.set_servo_angle(math.sin(t/500)*90+90)

        # while True:
        #     dc.set_servo_angle(0)
        #     time.sleep(3)
        #     dc.set_servo_angle(180)
        #     time.sleep(3)


        # Cleanup
        # dc.cleanup()

    except KeyboardInterrupt:
        print("Stopping...")
        dc.peltier_disable()
        dc.cleanup()

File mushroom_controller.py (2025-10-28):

import time
import threading
from enum import Enum
from dataclasses import dataclass
from typing import Dict, List, Optional
from datetime import datetime, time as dt_time, timedelta
import json
import logging
import csv
import os
from simple_pid import PID

from device_control import DeviceController
from CO2_sensor import get_CO2_data
from DS18B20 import get_DS_temp
from DHT22 import get_DHT22_data

# Configure logging
logging.basicConfig(level=logging.INFO, format='%(asctime)s - %(levelname)s - %(message)s')
logger = logging.getLogger(__name__)

class SystemState(Enum):
    STANDBY = "standby"
    ACTIVE = "active"
    ERROR = "error"

class LightSchedule:
    def __init__(self, start_time: dt_time, end_time: dt_time, colour: str = "off", 
                  neopixel_intensity: float = 0.0, white_intensity: float = 0.0, uv_intensity: float = 0.0):
        self.start_time = start_time
        self.end_time = end_time
        self.colour = colour
        self.neopixel_intensity = neopixel_intensity
        self.white_intensity = white_intensity
        self.uv_intensity = uv_intensity
    
    def is_active(self, current_time: dt_time) -> bool:
        return self.start_time <= current_time <= self.end_time

@dataclass
class ControlSetpoints:
    # Defaults 
    temperature: float = 20.0
    humidity: float = 85.0
    co2_max: float = 800.0
    light_schedules: List[LightSchedule] = None
    
    def __post_init__(self):
        if self.light_schedules is None:
            # Default light schedule: 8am to 5pm
            self.light_schedules = [
                LightSchedule(dt_time(8, 0), dt_time(17, 0), "off", 0.0, 0.0, 0.0)
            ]

class MushroomChamberController:
    def __init__(self):
        self.state = SystemState.STANDBY
        self.devices = DeviceController()
        self.setpoints = ControlSetpoints()
        self.system_start_time = None
        
        # Control temp parameters defaults
        self.temp_control_state = False
        self.temp_pid = PID(0.9, 0.0008, 0.5, setpoint=self.setpoints.temperature)
        self.temp_pid.output_limits = (-1.0, 0.13)  # Full range for heating/cooling
        self.temp_pid.auto_mode = True      # Enable anti-windup
        self.steady_state_bias = 0.0  
        self.last_stable_time = None
        self.temperature_stable_start_time = None
        self.temperature_stable = False

        # Humidity control state
        self.humidity_control_state = False
        self.humidifier_on_time = None  
        self.humidifier_runtime_limit = 5400  # 1 hour 30 min in seconds
        self.humidity_override_active = False
        self.humidity_override_start_time = None
        self.ventilation_phase_start_time = None
        self.humidity_history = []  # Track humidity trends

        # CO2 control state
        self.CO2_control_state = False
        
        # Ventilation control defaults
        self.vent_angle = 0  # 0=closed, 180=fully open
        self.vent_fan_speed = 0.0
        
        # Timing and state tracking defaults
        self.last_control_cycle = time.time()
        self.control_interval = 2.0  # seconds
        self.sensor_read_interval = 2.0
        
        # Current sensor readings with intialised values for startup
        self.current_temps = {"Probe1": 0.0, "Probe2": 0.0, "Probe3": 0.0, "DHT_Sensor":0.0, "CO2_Sensor":0.0,}
        self.current_humidity = 0.0
        self.current_co2 = 0.0
        
        # Threading
        self.control_thread = None
        self.running = False
        self.lock = threading.RLock()
        
        # Error tracking
        self.errors = []
        self.max_errors = 20 # Ammount of errors stored in buffer
        
        # Photo mode for timelapse
        self.photo_mode_active = False
        self.photo_mode_timeout = 0
        
        # Sensor health tracking
        self.sensor_errors = 0
        self.max_sensor_errors = 5
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

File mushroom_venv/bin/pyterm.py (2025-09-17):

#!/home/luke/mushroom_project/mushroom_venv/bin/python3

"""Simple Python serial terminal
"""

# Copyright (c) 2010-2024, Emmanuel Blot <emmanuel.blot@free.fr>
# Copyright (c) 2016, Emmanuel Bouaziz <ebouaziz@free.fr>
# All rights reserved.
#
# SPDX-License-Identifier: BSD-3-Clause

# pylint: disable=broad-except
# pylint: disable=wrong-import-position

from argparse import ArgumentParser, FileType
from atexit import register
from collections import deque
from logging import Formatter, StreamHandler, DEBUG, ERROR
from os import environ, linesep, stat
from re import search
from sys import exit as sys_exit, modules, platform, stderr, stdout
from time import sleep
from threading import Event, Thread
from traceback import format_exc
from _thread import interrupt_main

# pylint: disable=import-error
# pylint: disable=import-outside-toplevel

from pyftdi import FtdiLogger
from pyftdi.ftdi import Ftdi
from pyftdi.misc import to_bps, add_custom_devices
from pyftdi.term import Terminal


class MiniTerm:
    """A mini serial terminal to demonstrate pyserial extensions"""

    DEFAULT_BAUDRATE = 115200

    def __init__(self, device, baudrate=None, parity=None, rtscts=False,
                 debug=False):
        self._terminal = Terminal()
        self._device = device
        self._baudrate = baudrate or self.DEFAULT_BAUDRATE
        self._port = self._open_port(self._device, self._baudrate, parity,
                                     rtscts, debug)
        self._resume = False
        self._silent = False
        self._rxq = deque()
        self._rxe = Event()
        self._debug = debug
        register(self._cleanup)

    def run(self, fullmode=False, loopback=False, silent=False,
            localecho=False, autocr=False):
        """Switch to a pure serial terminal application"""

        self._terminal.init(fullmode)
        print(f'Entering minicom mode @ { self._port.baudrate} bps')
        stdout.flush()
        self._resume = True
        # start the reader (target to host direction) within a dedicated thread
        args = [loopback]
        if self._device.startswith('ftdi://'):
            # with pyftdi/pyusb/libusb stack, there is no kernel buffering
            # which means that a UART source with data burst may overflow the
            # FTDI HW buffer while the SW stack is dealing with formatting
            # and console output. Use an intermediate thread to pop out data
            # out from the HW as soon as it is made available, and use a deque
            # to serve the actual reader thread
            args.append(self._get_from_source)
            sourcer = Thread(target=self._sourcer, daemon=True)
            sourcer.start()
        else:
            # regular kernel buffered device
            args.append(self._get_from_port)
        reader = Thread(target=self._reader, args=tuple(args), daemon=True)
        reader.start()
        # start the writer (host to target direction)
        self._writer(fullmode, silent, localecho, autocr)

    def _sourcer(self):
        try:
            while self._resume:
                data = self._port.read(4096)
                if not data:
                    continue
                self._rxq.append(data)
                self._rxe.set()
        except Exception as ex:
            self._resume = False
            print(str(ex), file=stderr)
            interrupt_main()

    def _get_from_source(self):
        while not self._rxq and self._resume:
            if self._rxe.wait(0.1):
                self._rxe.clear()
                break
        if not self._rxq:
            return bytearray()
        return self._rxq.popleft()

    def _get_from_port(self):
        try:
            return self._port.read(4096)
        except OSError as ex:
            self._resume = False
            print(str(ex), file=stderr)
            interrupt_main()
            return bytearray()
        except Exception as ex:
            print(str(ex), file=stderr)
            return bytearray()

    def _reader(self, loopback, getfunc):
        """Loop forever, processing received serial data in terminal mode"""
        try:
            # Try to read as many bytes as possible at once, and use a short
            # timeout to avoid blocking for more data
            self._port.timeout = 0.050
            while self._resume:
                if self._silent:
                    sleep(0.25)
                    continue
                data = getfunc()
                if data:
                    stdout.write(data.decode('utf8', errors='replace'))
                    stdout.flush()
                if loopback:
                    self._port.write(data)
        except KeyboardInterrupt:
            return
        except Exception as exc:
            print(f'Exception: {exc}')
            if self._debug:
                print(format_exc(chain=False), file=stderr)
            interrupt_main()

    def _writer(self, fullmode, silent, localecho, crlf=0):
        """Loop and copy console->serial until EOF character is found"""
        while self._resume:
            try:
                char = self._terminal.getkey()
                if fullmode and ord(char) == 0x2:    # Ctrl+B
                    self._cleanup(True)
                    return
                if self._terminal.IS_MSWIN:
                    if ord(char) in (0, 224):
                        char = self._terminal.getkey()
                        self._port.write(self._terminal.getch_to_escape(char))
                        continue
                    if ord(char) == 0x3:    # Ctrl+C
                        raise KeyboardInterrupt('Ctrl-C break')
                if silent:
                    if ord(char) == 0x6:    # Ctrl+F
                        self._silent = True
                        print('Silent\n')
                        continue
                    if ord(char) == 0x7:    # Ctrl+G
                        self._silent = False
                        print('Reg\n')
                        continue
                if localecho:
                    stdout.write(char.decode('utf8', errors='replace'))
                    stdout.flush()
                if crlf:
                    if char == b'\n':
                        self._port.write(b'\r')
                        if crlf > 1:
                            continue
                self._port.write(char)
            except KeyError:
                continue
            except KeyboardInterrupt:
                if fullmode:
                    if self._terminal.IS_MSWIN:
                        self._port.write(b'\x03')
                    continue
                self._cleanup(True)
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

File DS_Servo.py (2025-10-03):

import threading
import time
from rpi_hardware_pwm import HardwarePWM

_SERVO_MAP = {
    "intake": (0, 0),
    "output": (0, 2),
}
_MIN_DC = 4.5
_MAX_DC = 10.0

_targets = {}
_servos = {}
_threads = {}
_running = True


def _angle_to_dc(angle):
    return _MIN_DC + (angle / 180.0) * (_MAX_DC - _MIN_DC)


def _servo_loop(name, chip, channel):
    pwm = HardwarePWM(pwm_channel=channel, hz=50, chip=chip)
    pwm.start(_angle_to_dc(90))  # start at 90
    _servos[name] = pwm
    _targets[name] = 90

    while _running:
        target = _targets[name]
        pwm.change_duty_cycle(_angle_to_dc(target))
        time.sleep(0.05)  # update rate


def start_servos():
    for name, (chip, channel) in _SERVO_MAP.items():
        t = threading.Thread(target=_servo_loop, args=(name, chip, channel), daemon=True)
        t.start()
        _threads[name] = t


def set_angle(name, angle):
    _targets[name] = max(0, min(180, angle))


def get_angle(name):
    return _targets.get(name)


def stop_servos():
    global _running
    _running = False
    for pwm in _servos.values():
        pwm.stop()

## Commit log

2025-09-01 Changed Camera file name, add temperature monitor
2025-10-03 Added servo library, added device controller lib
2025-10-03 Completed device controller library up to neos
2025-10-13 Working Mostly
    [mushroom_chamber_data.csv]
2025-10-15 UPdating PID
    [mushroom_chamber_data.csv]
2025-10-15 Updated PIDs
    [mushroom_chamber_data.csv]
2025-10-28 Updated comments
    [check.csv, mushroom_chamber_data.csv]
